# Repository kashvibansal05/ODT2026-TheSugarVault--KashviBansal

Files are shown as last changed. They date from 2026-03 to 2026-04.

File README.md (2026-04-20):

**Project Title**

The Sugar Vault

**📌 Project Overview**

The project is an arcade-style claw machine with three-axis movement (X, Y, Z) and a servo-controlled claw that picks up candy and drops it at a fixed location. It is coin-operated, triggering sound and LED effects to simulate a real arcade game experience.

**📂 Repository Structure**
1. Electronics Details
2. Mechanical Details
3. Software Details
4. Project Documents
5. Media

**⚙️ How to Navigate This Repository**

Electronics Details → Circuit, components justification

Mechanical Details → Sketches, CAD, and fabrication

Software Details → Code, logic, and implementation

Project Documents → Design thinking, planning, testing

Media → Weekly progress and final output

**👥 Team Members**

Kashvi Bansal

Ashmita Gupta

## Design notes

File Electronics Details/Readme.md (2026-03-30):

📂 **Contents of the Folder**
1 Electronic Details Document
2 Circuit Diagram

⚠️ **Guidelines**
Ensure diagrams are neat and readable
Can be hand-drawn or software-generated
Should match actual implementation
Justification of components is mandatory

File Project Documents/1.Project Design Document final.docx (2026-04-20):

# Project Design Document

### 1. Design Intent

- What experience are you trying to create?

The aim is to recreate the excitement and interaction of a classic arcade claw machine. The experience is designed to feel engaging and rewarding, with responsive controls, visual feedback, and sound cues that make gameplay immersive and enjoyable.

- Who is it for?

The machine is designed for a wide age group (10–50+ years), including students, young adults, and older users. It is simple and intuitive enough for first-time users, while still offering a fun challenge that appeals across age groups.

- If solving a problem, what problem does it solve?

The project explores how physical interaction and simple mechanics can create engaging user experiences. It addresses the challenge of translating a familiar arcade interaction into a functional, small-scale prototype while balancing usability, feedback, and mechanical limitations.

### 2. Inspiration & References

- Inspiration

https://www.instructables.com/Arduino-Claw-Machine/

https://www.hackster.io/theSTEMpedia/candy-claw-machine-arduino-based-arcade-game-f51ee6

https://www.youtube.com/watch?v=XqT0NzsYdEA

- What did you learn from them?
  - From the Instructables project, we understood how a claw machine can be designed as a complete system with gantry movement, servo-based gripping, and a timer-based game loop. It also showed how real arcade machines rely more on timing and control rather than just randomness.
  - From the Hackster project, we learned about the integration of multiple components like joystick control, motors, sensors, and feedback systems. It helped us understand how XY movement, vertical motion, and claw control can work together in a structured way.
  - From the YouTube reference, we got a clearer idea of the user experience and physical interaction, especially how lights, sound, and rewards (like candy) make the system more engaging and game-like.

### 3. User Journey

Step-by-step experience of the user:

1. User approaches the machine and inserts a coin
2. System responds with arcade sound and LED animation → game begins
3. User grabs the joystick and starts moving the claw, exploring the space
4. User looks for a target while the timer runs in the background
5. User positions the claw and presses the button
6. System takes over → claw opens, moves down, grabs, and lifts up
7. Claw automatically moves to the drop zone
8. Claw releases the object
9. System checks result → brief moment of anticipation
10. System responds:
- Green lights + sound → user wins
- Red lights + sound → user loses
11. User reacts and collects reward (if won)
12. System resets and waits for the next user

### 4. Success Criteria

- Functional

Claw responds to joystick input within < 0.5–1 second

Servo completes open/close action within ≤ 1.5 seconds

LED and sound feedback trigger within < 0.5 seconds of coin insertion or result

Ultrasonic sensor detects object accurately within ≤ 10 cm range with ≥ 90% accuracy

- User experience

Users able to understand joystick controls within < 1 minute

Successful object pickup achieved in at least 3 out of 5 attempts

Movement remains smooth with minimal jitter during continuous use (≥ 1 minute)

- Reliability

System runs without failure for at least 5 consecutive trials

No major lag or crash during 1-minute gameplay cycle

Sensor and motor performance remains consistent with ≤ 10% variation across trials

### 5. System Overview

- High-level explanation of system

The system is a coin-operated claw machine controlled by an ESP32, where the game begins when a coin is detected using an IR sensor. Once triggered, the system activates a timed gameplay sequence, allowing the user to control the claw’s movement using a joystick. On pressing a button, an automated sequence controls the claw to move down, grab an object using a servo, and return to its original position. The claw then moves to a fixed drop location, where an ultrasonic sensor checks if the object has been successfully collected. Based on this, the system provides visual (LED) and audio (buzzer) feedback for win or loss, and resets itself for the next user.

- What are the main parts?
  - Input System: IR sensor, joystick, push button, ultrasonic sensor
  - Processing Unit: ESP32 running MicroPython to handle logic, timing, and sequencing
  - Mechanical System: DC motors (gantry movement), servo motor (claw), thread and pulley mechanism
  - Output System: NeoPixel LEDs (visual feedback), buzzer (audio feedback)

### 6. High-Level Block Diagram

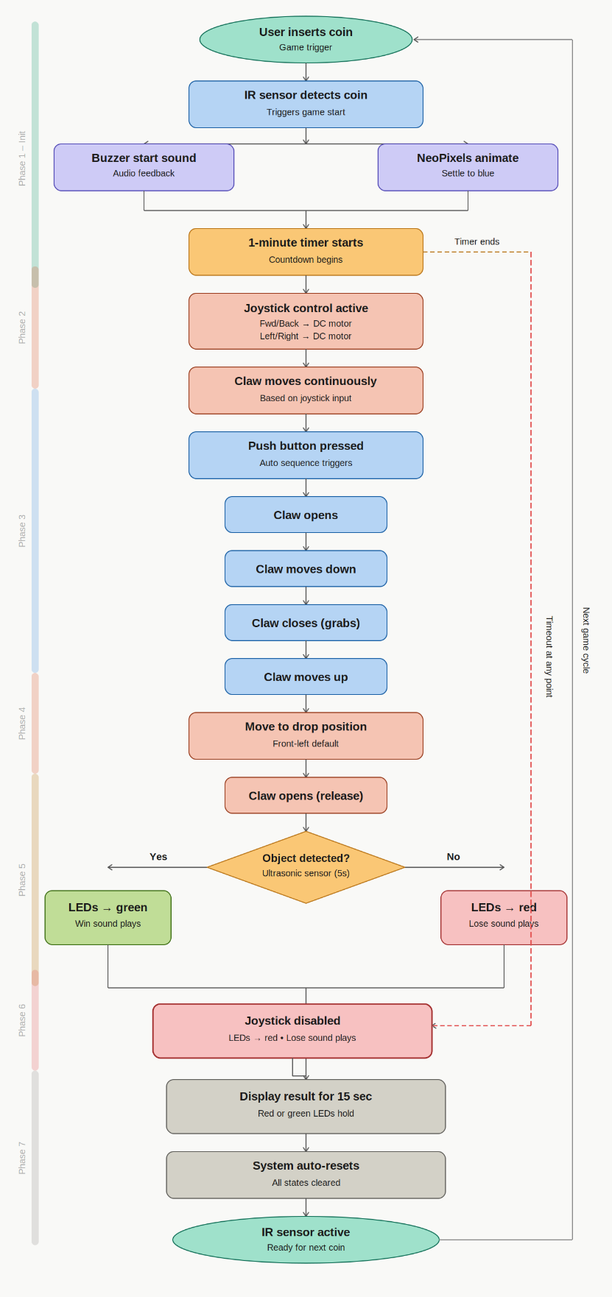
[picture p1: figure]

### 7. Input / Output Mapping

Input | Process | Output
IR Sensor | Detects coin insertion and triggers game start sequence | Buzzer plays start sound, NeoPixel LEDs animate and turn blue, timer starts
Joystick | Reads directional input (analog values) and maps it to motor movement | DC motors move claw forward/backward and left/right
Push Button | Triggers automated claw sequence | Claw opens → moves down → closes → moves up (DC motor + Servo motor)
Ultrasonic Sensor | Measures distance to detect presence of object in collection area | Determines win/lose → LEDs turn green/red, buzzer plays corresponding sound
Timer (1 minute) | Tracks gameplay duration | Triggers losing condition (red LEDs + buzzer)

### 8. Sketches & Concepts

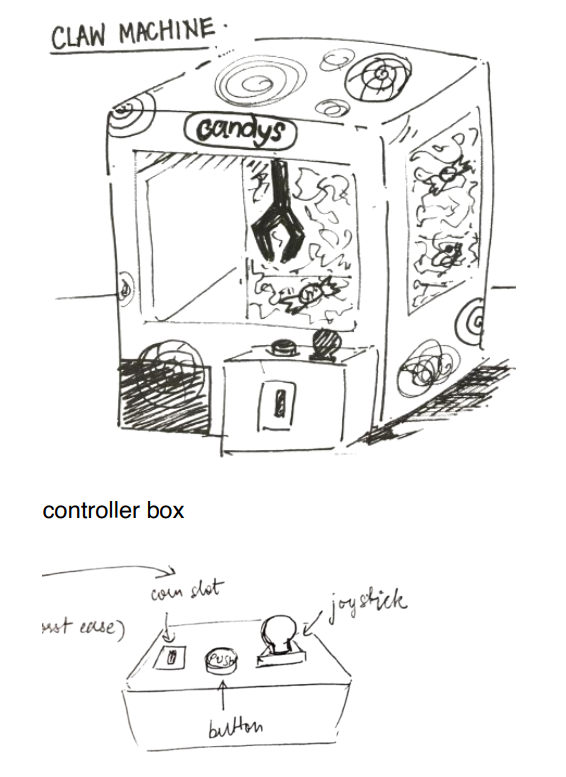
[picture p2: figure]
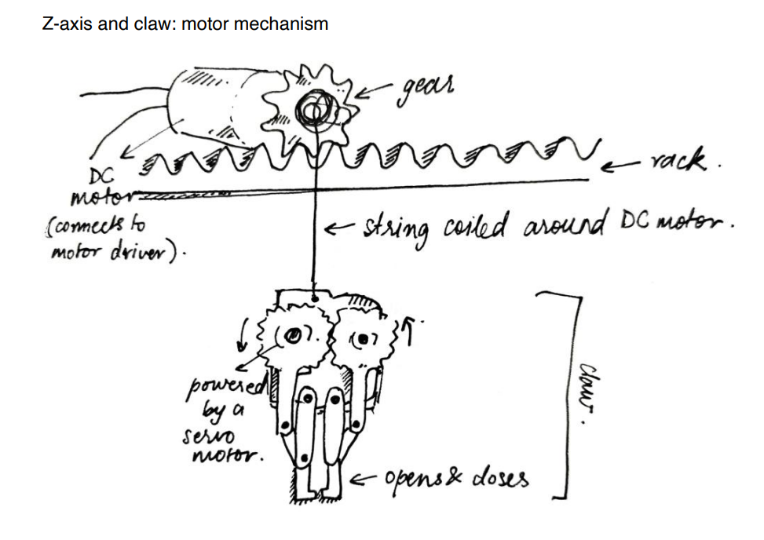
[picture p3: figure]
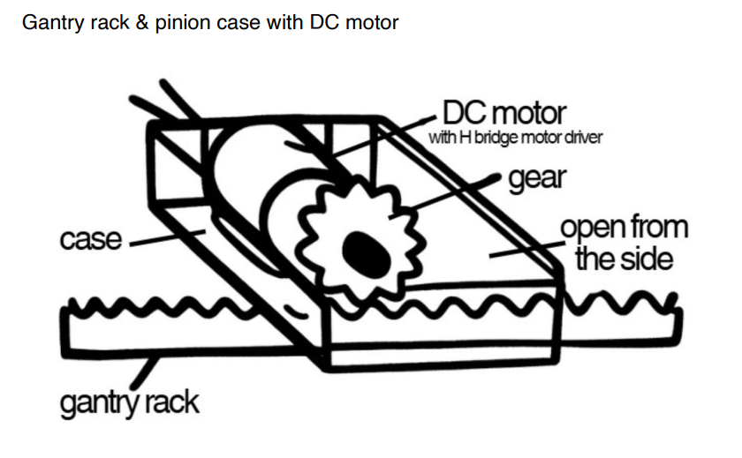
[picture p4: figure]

### 9. Final System Architecture (Labelled)

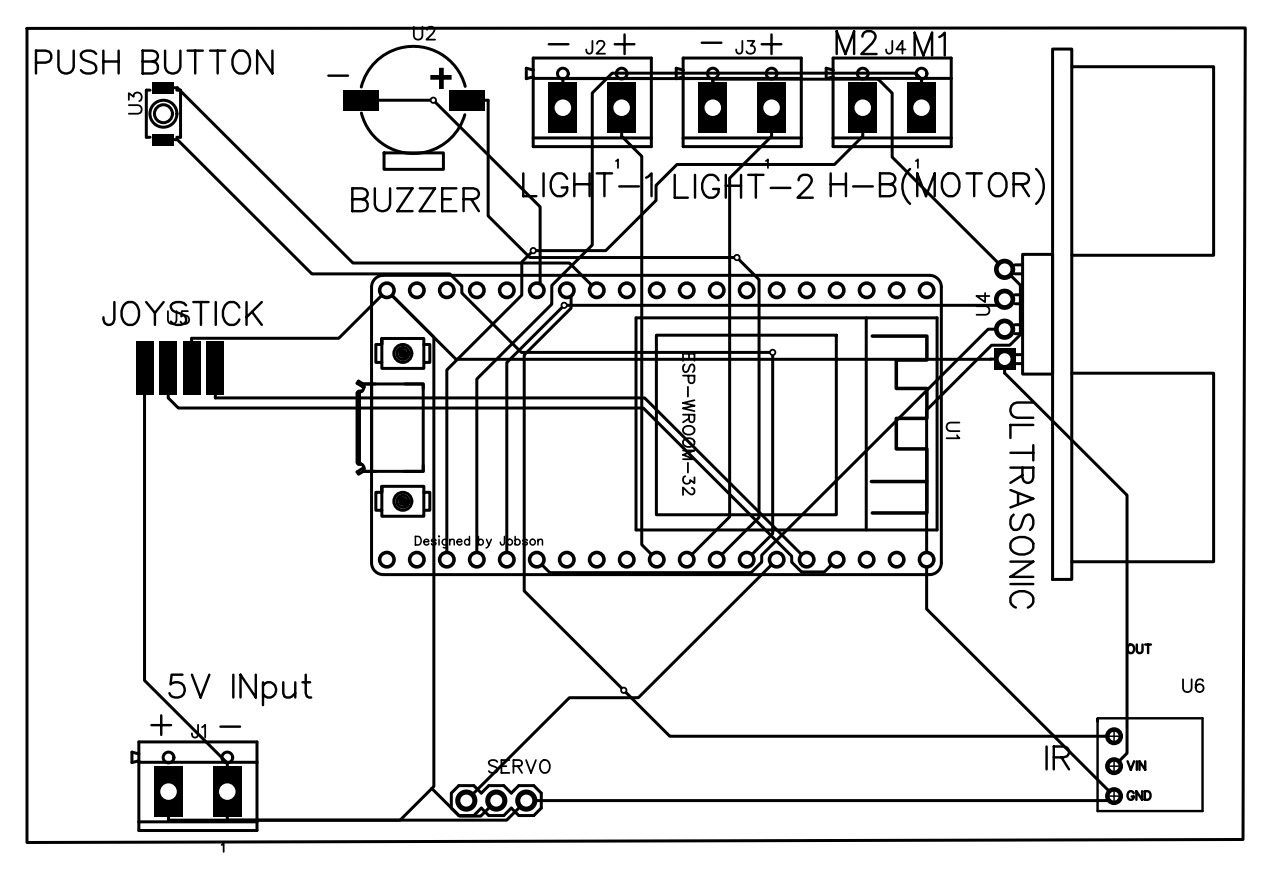
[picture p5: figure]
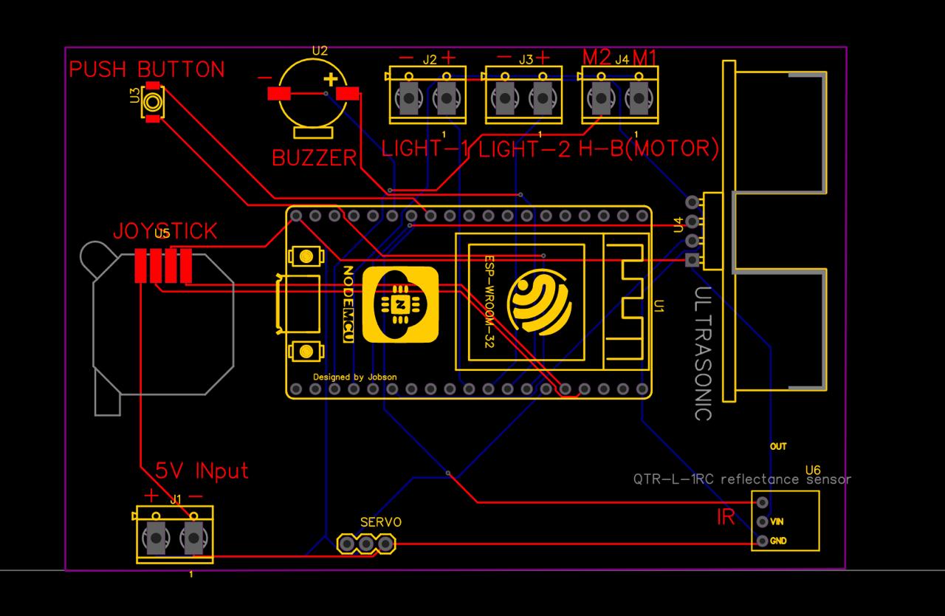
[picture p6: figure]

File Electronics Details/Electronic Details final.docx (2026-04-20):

# Electronics Documentation

### 1. Electronics Block Diagram

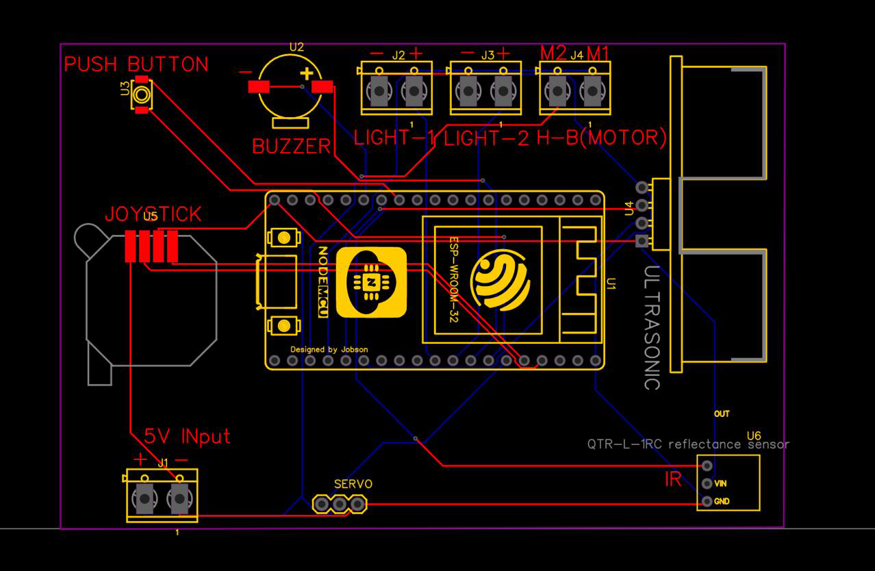
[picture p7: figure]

### 2. Components Table

Component | Quantity | Purpose | Justification
DC Motor | 3 | To move the claw along all 3 axis (left-right, front-back and up-down) | DC geared motors provide high torque at low speeds, which is essential for lifting the claw and moving loads smoothly
Servo Motor | 1 | To open and close the claw | Servo motors allow precise angle control, which is required to accurately grip and release objects
Joystick | 1 | To enable the user to navigate the claw to the desired location | A joystick provides intuitive 2-axis control, making it easy for users to control movement
Neopixel strip | 2 | To enhance user experience and indicate game status (win/lose) | NeoPixels are individually addressable allowing programmable animations and color patterns for visual feedback during the game
IR Obstacle Detection Sensor | 1 | To detect the coin and start the game | IR sensors provide fast output at short ranges without any physical contact
Ultrasonic sensor | 1 | To detect if an object is successfully dropped or not. | Ultrasonic sensors enable accurate detection of whether an object has reached the collection bin. (Unlike IR sensors, its performance is not affected by object color or surface reflectivity. This makes it more accurate for detecting objects of varying shapes and materials in an open space.)
Push Button | 1 | To allow user drop the claw and attempt to collect the object | Provides a simple and reliable input mechanism for triggering the claw action
Buzzer | 1 | To provide audio feedback for the game events | Sound feedback enhances user interaction and makes the game more engaging.

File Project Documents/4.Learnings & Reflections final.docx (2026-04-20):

# Learnings & Reflections Document

### 1. Team Reflection

- How did the team work together?

There was a clear division of work with mutually agreed roles and responsibilities. Our brainstorming and ideation were well aligned, which made decision-making smoother. During execution, instead of completely splitting tasks, we often worked together, which helped maintain consistency. We also supported each other throughout the process and boosted each other’s morale during setbacks.

- What worked well?

Working on the same tasks together brought in different viewpoints and improved the overall output. We met regularly, spent a few hours each day working on the project, and maintained clear communication. During failures, instead of panicking, we focused on quickly finding solutions and moving forward.

- What could be improved?

We could have planned for worst-case scenarios and kept backup options ready. Testing major components earlier would have reduced last-minute stress. Better time management and slightly more structured task division could have made the process more efficient.

### 2. Technical Reflection

- Key technical challenges
- Researching and deciding the most suitable mechanism for movement with limited resources
- Selecting the right motors based on torque and requirement
- Overloading the power module, which caused it to burn multiple times
- Integrating all components neatly within the physical structure
- What did you learn (hardware/software)?
- Learned how to program and control a joystick from scratch
- Explored NeoPixel LEDs beyond basic use, shifting from a ring to a strip for better effects
- Understood how servo motors provide precise angular control for small, accurate movements
- Realized the importance of circuit optimization and stable connections for reliable performance
- Gained experience in coordinating multiple inputs and outputs within one system
- Mistakes & debugging experiences
- Did not initially account for the weight of the DC motor, which affected gantry stability
- Left full system integration testing too late
- Missed adding the cap on ENA in the motor driver, leading to long debugging confusion
- Loose wiring (especially in the motor driver) caused inconsistent behavior
- A messy circuit made debugging more difficult and time-consuming

### 3. Design Reflection

- Did the experience match your intention?

Yes, the final outcome successfully recreated the feel of an arcade claw machine, especially through the interaction, feedback, and reward system.

- What would you improve?
- Better concealment and organization of the circuitry
- Use of stronger and cleaner assembly methods (adhesives, joints)
- User feedback insights
- Users found the design very attractive and similar to real arcade machines
- The candy reward and overall look made it feel fun and engaging
- Feedback suggested improving movement control (especially full X-Y range) for a more realistic experience

### 4. Personal Reflection

Kashvi’s Reflection:

- What I learned

I learned how to bring together a wide range of inputs and outputs and make them work as one system. This project also made me understand the importance of proper planning, continuous testing, and multiple iterations when building something complex.

- What I struggled with

Deciding the gantry mechanism was challenging, and even after finalizing it, the DC motor turned out to be too heavy, which affected the structure. I realized I should have planned and considered such details earlier and measured more accurately. We also should have tested the circuit in smaller sections before full integration. Additionally, managing sequences where one input triggers multiple outputs was tricky and required patience to debug.

- What I am proud of

We faced issues almost every day, but instead of giving up, we found practical “jugaad” solutions to keep moving forward. I’m proud of learning new components like the joystick from scratch and successfully coding it. I also value the amount of brainstorming that went into enhancing the experience by constantly thinking what more can I add. This project pushed me to apply physics (which I didn’t think I would ever use again), design thinking, and an engineering mindset in a way I hadn’t before, which makes the whole journey really meaningful to me.

Ashmita’s Reflection:

- What I learned

Through this project, I learned how multiple hardware components like DC motors, servo motors, sensors, and microcontrollers can be integrated into one working system. It also helped me understand how coding and physical mechanisms depend on each other. Most importantly, I realized that something working in theory does not always translate directly into a successful real-world implementation.

- What I struggled with

One of the biggest challenges I faced was integrating hardware and software smoothly. Issues like the gantry not supporting the motor weight and unstable sensor readings made debugging difficult. It was also challenging to identify whether problems were caused by code, wiring, or mechanical design, which required a lot of trial and error and patience.

- What I am proud of

I am proud that I was able to successfully build a working claw machine with multiple integrated features. The joystick control, claw mechanism, LED feedback, and overall interaction worked well together. Despite facing technical and mechanical challenges, the project came together as a functional and engaging system, which made the entire process feel rewarding.

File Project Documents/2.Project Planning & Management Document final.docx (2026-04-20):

# Project Planning & Management Document

### 1. Project Overview

- Project Title: The Sugar Vault
- Team Members & Roles: Ashmita Gupta & Kashvi Bansal
- Brief Description: The project is an arcade-style claw machine with three-axis movement (X, Y, Z) and a servo-controlled claw that picks up candy and drops it at a fixed location. It is coin-operated, triggering sound and LED effects to simulate a real arcade game experience.

### 2. Team Roles & Responsibilities

Member Name | Role | Responsibilities
Ashmita Gupta | Primary: - Coding + code testing - Physical model making - Mechanical design Secondary: - Circuit making - documentation | Developed and tested code for system functionality and control logic. Led building the physical model and designing & developing mechanical components like the gantry, gantry case and claw. Assisted in circuit setup and supported documentation of the project process.
Kashvi Bansal | Primary: - Coding + code testing - Circuit Making - documentation Secondary: - Physical model making - Mechanical design | Worked on coding and testing system behavior, ensuring smooth integration of inputs and outputs. Managed circuit making, connections and wiring for reliable performance. Led documentation efforts while also contributing to model building and mechanical design.

### 3. Project Timeline & Milestones

Week | Goals | Deliverables | Status
Week 0 | Finalize concept, research gantry & claw mechanism, and plan components | Initial idea, sketches, and list of components | Completed
Week 1 | Build physical model and design (3d modelling) and develop mechanical systems (gantry + claw) | Partial structure, gantry setup, initial claw mechanism | Completed
Week 2 | Integrate electronics and coding (joystick, motors, servo, sensors, LED strip, buzzer) and testing | Working prototype with joystick control, claw action, and feedback systems | Completed

### 4. Weekly Progress Log

Week 0:

Category | Details
Planned tasks | Finalize project idea, research claw mechanisms, and plan components
Completed tasks | Selected claw machine concept, researched rack and pinion system, listed components
Challenges faced | Difficulty in translating the concept into a practical mechanical system
Solutions | Broke the system into smaller parts and planned each component separately
Next steps | Begin building the physical model and gantry structure

Week 1:

Category | Details
Planned tasks | Design and build gantry mechanism and claw structure and physical model making
Completed tasks | Constructed gantry and integrated DC motors, designed servo-based claw, finished the basic physical structure of the machine
Challenges faced | Gantry failed in X and Y axes due to heavy DC motor weight
Solutions | Focused on partial functionality (Z-axis) and continued development of other components
Next steps | Start coding and integrate joystick and motor control

Week 2:

Category | Details
Planned tasks | Complete coding and integrate all components
Completed tasks | Implemented joystick control, claw movement, LED and sound feedback, ultrasonic detection, final circuit and assembly
Challenges faced | While individual components worked well independently, integrating them into a single system led to unexpected errors. The joystick was slightly sensitive, and the claw grip was weak. Additionally, the large number of connections on the breadboard made it difficult to identify faulty wiring, and the power module getting stolen on the final day disrupted testing.
Solutions | Systematically tested and debugged each component within the integrated setup to isolate issues and improved wiring organization to simplify troubleshooting.
Next steps | Conduct user testing and finalize documentation

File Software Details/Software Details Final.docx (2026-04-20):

# Software Documentation

### 1. Software Overview

- What does the software do?

The software controls the complete working of the claw machine, starting from coin detection to gameplay, object retrieval, and result indication. It processes inputs from the IR sensor (coin detection), joystick (movement control), push button (claw activation), and ultrasonic sensor (object detection). Based on these inputs, the program executes logic to control outputs such as DC motors (movement), servo motor (claw operation), NeoPixel LEDs (visual feedback), and buzzer (audio feedback). It ensures smooth gameplay within a fixed time limit and automatically resets the system for the next user.

- Platforms used

MicroPython (Thonny) - for programming the ESP32 microcontroller

ESP32 - main controller handling all inputs and outputs

### 2. System Logic

Phase 1: Initialization (Game Start)

1. User inserts coin
2. IR sensor detects coin
3. Buzzer plays start sound
4. NeoPixel LEDs animate and then stay blue
5. 1-minute timer starts

Phase 2: User Control (Movement Phase)

6. User controls claw using joystick:
  - Forward/Backward → DC motor (clockwise and anticlockwise)
  - Left/Right → DC motor (clockwise and anticlockwise)
7. Claw moves continuously based on input

Phase 3: Claw Operation (Pickup Phase)

8. User presses push button
9. Automatic sequence begins:
  - Claw opens
  - Claw moves downward
  - Claw closes (grabs object)
  - Claw moves upward

Phase 4: Transfer & Drop Phase

10. Claw moves to front-left drop default position
11. Claw opens to release object

Phase 5: Result Detection Phase

12. Ultrasonic sensor checks for object in collection area
- If object detected: → LEDs turn green → Winning sound plays
- If object not detected (within 5 seconds): → LEDs turn red → Losing sound plays

Phase 6: Timeout Condition

13. If 1-minute timer ends at any point:
- Joystick control is disabled
- LEDs turn red
- Losing sound plays

Phase 7: Reset Phase

14. Result (red/green LEDs) is displayed for 15 seconds
15. System resets automatically
16. IR sensor becomes active for next coin

### 3. Flowchart

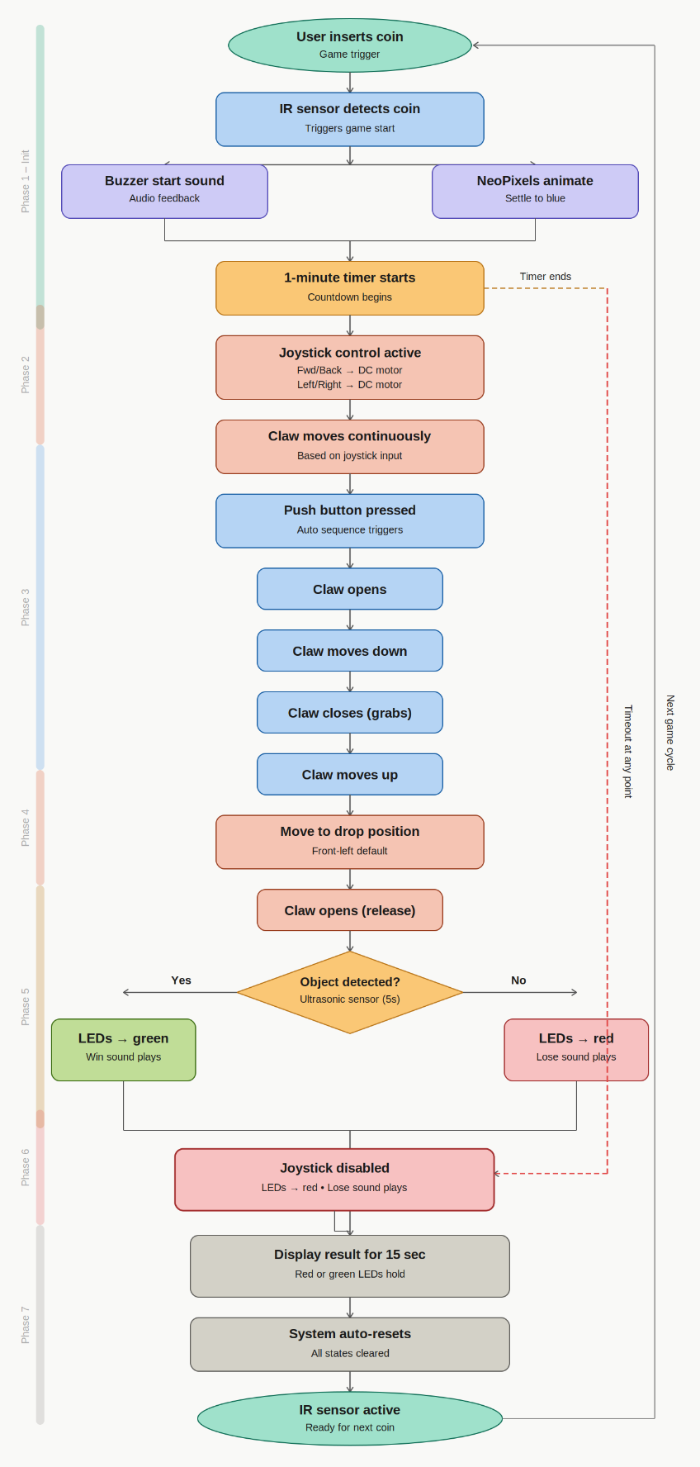
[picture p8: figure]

### 4. App Flow (If MIT App Inventor)

Not applicable (The system is fully hardware controlled using joystick and push button inputs. No mobile application or wireless communication is used)

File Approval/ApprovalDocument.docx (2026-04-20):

ODT Summative 2

Idea Brief :

The project is an arcade-style claw machine capable of full three-axis movement (X, Y, and Z), where the claw mechanism opens and closes to grip candy placed inside the play area. Once a piece of candy is grabbed, the claw travels to a fixed drop position every time, releasing the object consistently into a collection chute. The machine is coin-operated; inserting a coin triggers the start of the game, activating an audio cue and illuminating internal LEDs to signal that play has begun, replicating the experience of an arcade game.

Basic Idea Sketch :

Claw machine design

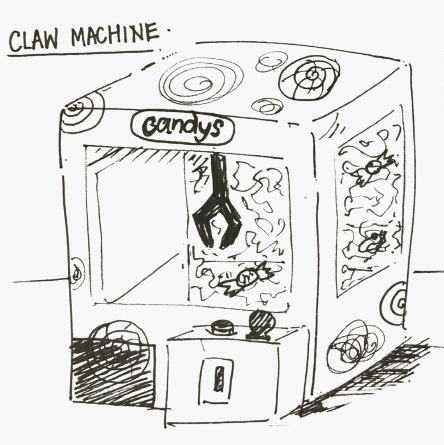
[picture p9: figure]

Gantry design

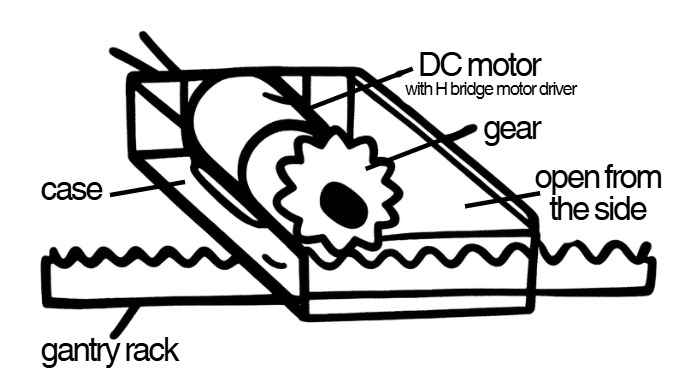
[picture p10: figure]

Controller box

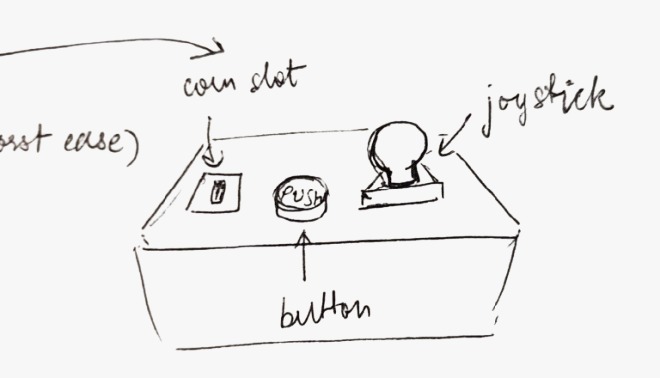
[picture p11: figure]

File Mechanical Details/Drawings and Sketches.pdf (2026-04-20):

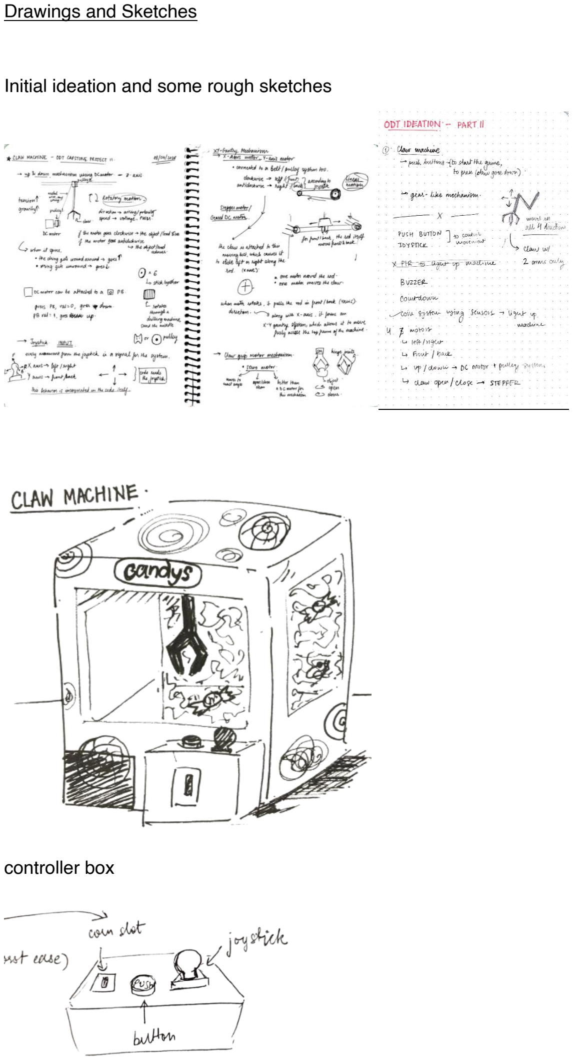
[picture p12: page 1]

Drawings and Sketches

Initial ideation and some rough sketches

controller box

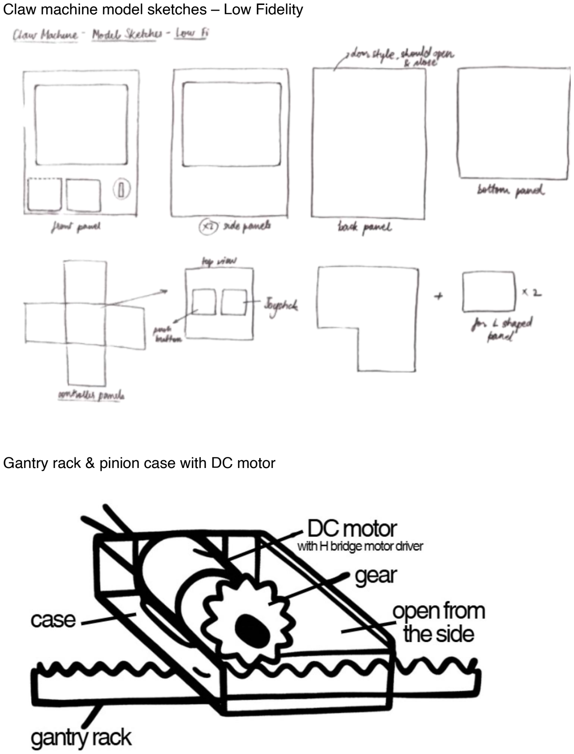
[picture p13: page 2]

Claw machine model sketches – Low Fidelity

Gantry rack & pinion case with DC motor

Z-axis and claw: motor mechanism

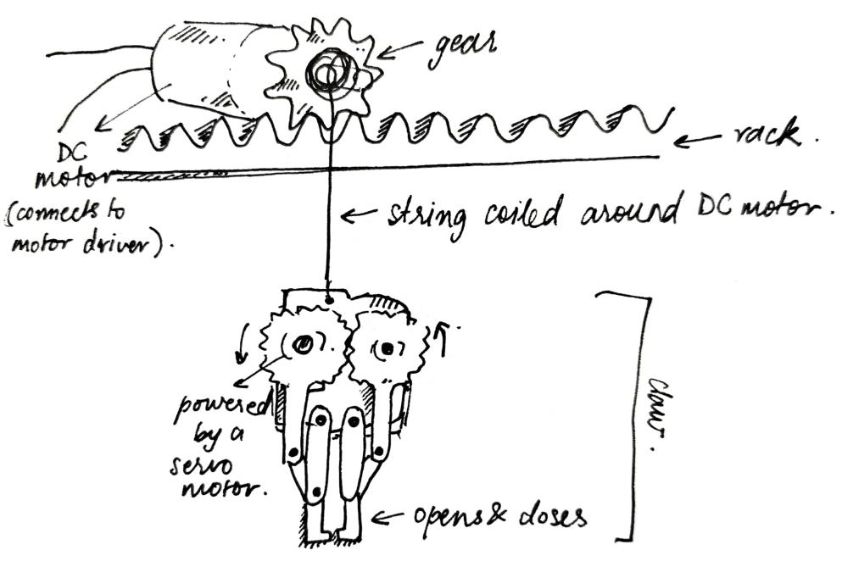
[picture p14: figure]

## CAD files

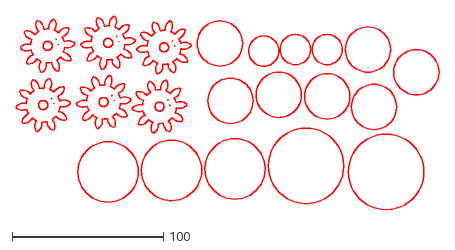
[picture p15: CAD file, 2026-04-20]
Mechanical Details/3D and laser cut files/Gantry laser cut design.dxf
279.9 x 128.0

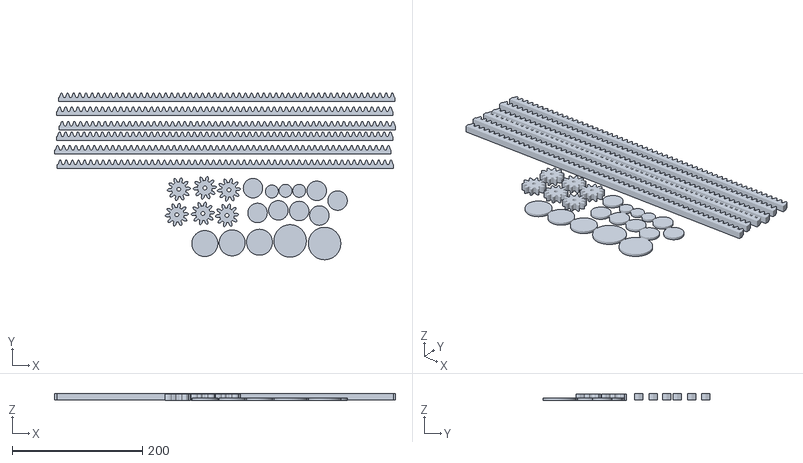
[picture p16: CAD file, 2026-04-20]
Mechanical Details/3D and laser cut files/3D modelled gantry parts.stl
524.0 x 256.0 x 11.5

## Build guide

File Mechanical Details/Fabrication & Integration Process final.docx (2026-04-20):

# Fabrication and Integration Process

### 1. Material Choice Justification:

- Cardboard for Main Structure: Chosen because it is lightweight, flexible, and easy to work with. It allowed quick building and changes during the making process.
- Chart Paper over Paint: Used for a cleaner and neater finish. It was faster than painting and easier to fix when mistakes happened.
- MDF for Claw & Gantry: Selected because it is stronger and more stable while still being relatively lightweight. It can handle the load and movement better than cardboard.
- Why Not 3D Printing: Although we designed parts for it, we didn’t use it due to time constraints and limited lab access. MDF was a more practical and quicker option, and also more sustainable in this case.

2. Fabrication Steps:

i. Made necessary cutouts on the front face of the cardboard box for the visual structure of the claw machine
ii. Built a separate box for the control panel (joystick, button, insert coin)
iii. Designed and laser cut the gantry and claw components
iv. Fitted and aligned the laser-cut gantry structure inside the cardboard frame
v. Assembled the claw by joining and screwing the parts together
vi. Attached the claw to a thread mechanism connected to the DC motor for vertical movement

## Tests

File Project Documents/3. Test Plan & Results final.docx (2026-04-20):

# Test Plan & Results

### 1. Test Plan

Test | Method | Expected Result
Gantry Mechanism (Rack & Pinion) | Tested movement across X, Y, and Z axes using DC motors | Smooth and stable movement in all directions
Joystick + DC Motor Control | Moved joystick in all four directions | Accurate and responsive movement
Claw Mechanism (Servo) | Triggered claw using button | Claw opens, goes down, grips, and lifts object

### 2. User Testing

- Users:
  - Classmates
  - first-time users
  - self
- Tasks given:
  - Insert coin to start the game
  - Move claw using joystick (all directions)
  - Pick up an object and drop it

### 3. Results

Test | Outcome | Pass/Fail
Gantry Mechanism (Rack & Pinion) | Worked well in theory, but in practice the DC motor weight was too high, causing failure in X and Y axis movement | fail
Joystick + DC Motor Control | Successfully integrated for all four directions; movement was smooth though slightly sensitive | Pass
Claw Mechanism (Servo) | Servo-based opening and closing worked smoothly, but grip strength was inconsistent | Pass

### 4. Observations

- User behavior:
  - Users quickly understood how to operate the joystick
  - Movement felt smooth and intuitive
  - Interaction was engaging and easy to learn
- Pain points:
  - The gantry structure could not support the weight of the DC motors, affecting X and Y movement. The added weight of the DC motors placed excessive load on the gantry system, causing instability and preventing smooth movement along the X and Y axes. This highlighted a mismatch between the structural strength of the frame and the mechanical load it was expected to carry.
  - Claw grip was not always strong enough to securely hold objects. While the servo-controlled mechanism functioned smoothly, the claw did not consistently apply enough force to firmly grasp objects. As a result, objects were sometimes dropped during lifting or movement, affecting the reliability of the system.

### 6. Improvements Suggested

- Gantry Mechanism: Replace heavy DC motors with lighter alternatives (like stepper motors) or redesign the structure to better support weight and improve stability.
- Claw Grip: Improve grip by redesigning the claw shape, adding rubber tips, or increasing servo torque for a stronger hold.
- Motor Efficiency: Optimize motor speed and timing for smoother and more precise movement.
- Overall Stability: Strengthen the frame and balance weight distribution to ensure consistent performance across all axes.

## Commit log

2026-04-20 Electronics Details and Circuit Diagram
2026-04-20 Create 3D and laser cut filed.md
2026-04-20 Create 3D Printing files
